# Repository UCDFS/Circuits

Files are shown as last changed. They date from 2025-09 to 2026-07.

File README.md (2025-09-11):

# UCDFS Circuits Repository

Welcome to the University College Dublin Formula Student (UCDFS) KiCad circuits repository! This is the central location for all our electronic circuit designs, schematics, and PCB layouts.

## About

This repository contains KiCad project files for various electronic circuits used in our Formula Student vehicle and projects. All designs are created using KiCad, an open-source electronic design automation (EDA) suite.

## Getting Started

1. **Clone this repository:**
   ```bash
   git clone https://github.com/UCDFS/Circuits.git
   cd Circuits
   ```

2. **Open a project in KiCad:**
   - Launch KiCad
   - Open the `.kicad_pro` file for the project you want to work on
   - The schematic (`.kicad_sch`) and PCB layout (`.kicad_pcb`) will be accessible from the project manager

3. **View/Edit Schematics:**
   - Click "Schematic Editor" in KiCad's main window
   - Or directly open the `.kicad_sch` file

4. **View/Edit PCB Layout:**
   - Click "PCB Editor" in KiCad's main window
   - Or directly open the `.kicad_pcb` file

## Repository Structure

```
├── README.md                     # This file
├── .gitignore                    # Git ignore rules for KiCad projects
└── [Project Name]/               # Individual circuit projects
    ├── [Project].kicad_pro       # KiCad project file
    ├── [Project].kicad_sch       # Schematic file
    └── [Project].kicad_pcb       # PCB layout file
```

## Contributing

When contributing new circuits or modifications:

1. **Create a new branch** for your work
2. **Organize projects** in clearly named directories
3. **Follow naming conventions:** Use descriptive names for projects and files
4. **Include all necessary files:** Ensure `.kicad_pro`, `.kicad_sch`, and `.kicad_pcb` files are included
5. **Document your work:** Add project details to a README in each circuit subfolder

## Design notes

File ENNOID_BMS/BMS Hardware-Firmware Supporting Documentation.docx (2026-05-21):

Main Master Slave IsoSPI configuration with detailed analysis on pin setup

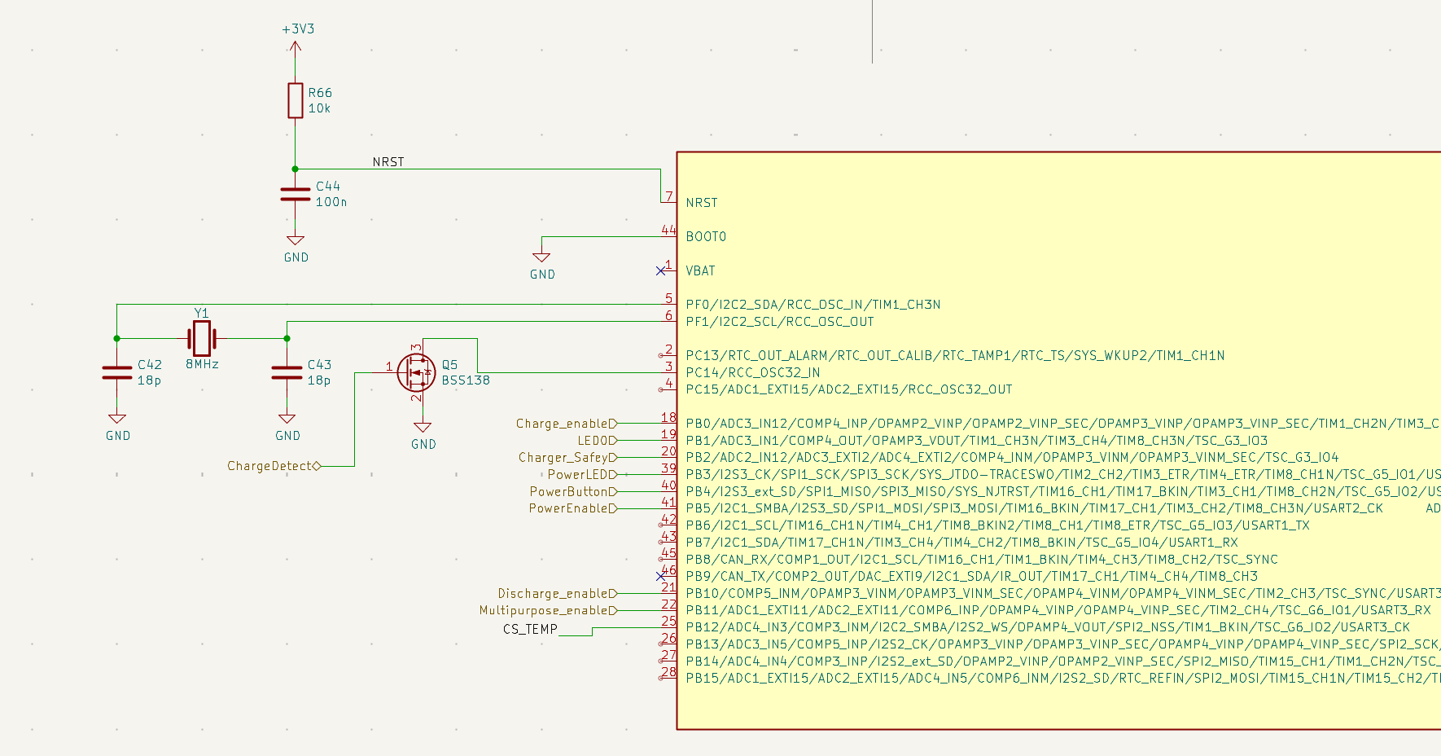
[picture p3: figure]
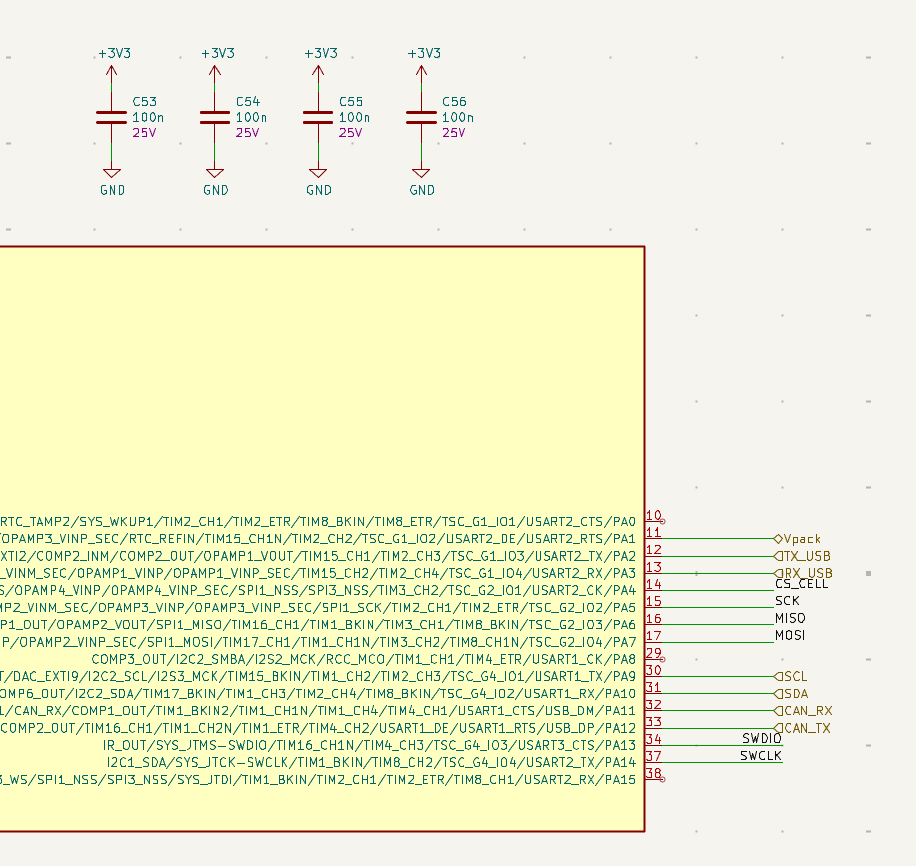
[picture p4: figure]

Fig 1 & 2. Master board STM32 pin configuration

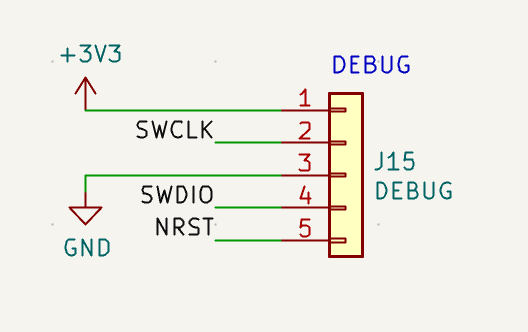
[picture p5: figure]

Fig 3. Flashing/Debug input connector

The STM32F303 is the master-board controller. It runs the BMS state machine, communicates with both isoSPI chains, reads local analogue/digital status signals, controls enable/safety outputs, and provides CAN/USB/debug interfaces. It is powered from +3V3, uses an 8 MHz HSE crystal, boots from user Flash with BOOT0 tied low, and is programmed/debugged through SWDIO/SWCLK.

Signal | STM32 pin | Type | Firmware role
CS_CELL | PA4 | SPI CS output / GPIO output | Selects the cell-chain LTC6820. Active-low chip select.
CS_TEMP | PB12 | SPI CS output / GPIO output | Selects the temperature-chain LTC6820. Active-low chip select.
SCK | PA5 | SPI bus | Shared SPI clock to both LTC6820 bridges.
MISO | PA6 | SPI bus | Shared SPI data from selected LTC6820 back to STM32.
MOSI | PA7 | SPI bus | Shared SPI data from STM32 to selected LTC6820.
Vpack | PA1 | ADC input | Load-side HV bus measurement after contactors/precharge.
ChargeDetect | PC14 | GPIO input | Charger present / charger wake reason.
Charge_enabled | PB0 | GPIO output | Charge permission/control output.
LED0 | PB1 | GPIO output | Status LED / indicator output.
Charger_Safety | PB2 | GPIO output | Charger safety/permission output.
PowerLED | PB3 | GPIO output | Power/status LED output.
PowerButton | PB4 | GPIO input | User power-button monitor input.
PowerEnable | PB5 | GPIO output | Firmware power latch / keep-alive output.
Discharge_enable | PB10 | GPIO output | Firmware discharge permission into the shutdown circuit. Downstream signal is active-low through the MOSFET stage. This is not a direct discharge relay driver.
Multipurpose_enable | PB11 | GPIO output | Firmware permission output into shutdown circuit. Downstream signal is active-low through the MOSFET stage. This replaces the old ENNOID precharge meaning and must not be used as a precharge relay output.
TX_USB | PA2 | UART TX | USB debug/config UART transmit to CP2104.
RX_USB | PA3 | UART RX | USB debug/config UART receive from CP2104.
SCL | PA9 | I²C SCL | I²C clock for ISL28022 / local I²C devices.
SDA | PA10 | I²C SDA | I²C data for ISL28022 / local I²C devices.
CAN_RX | PA11 | CAN RX | Vehicle CAN receive.
CAN_TX | PA12 | CAN TX | Vehicle CAN transmit.
SWDIO | PA13 | Debug | Serial Wire Debug data/programming.
SWCLK | PA14 | Debug | Serial Wire Debug clock/programming.
NRST | NRST pin | Reset | Active-low MCU reset; pulled up by 10 kΩ and filtered by 100 nF.
BOOT0 | BOOT0 pin | Boot config | Tied low, so MCU boots from user Flash.
HSE crystal | PF0/PF1 | Clock | 8 MHz external crystal input/output.

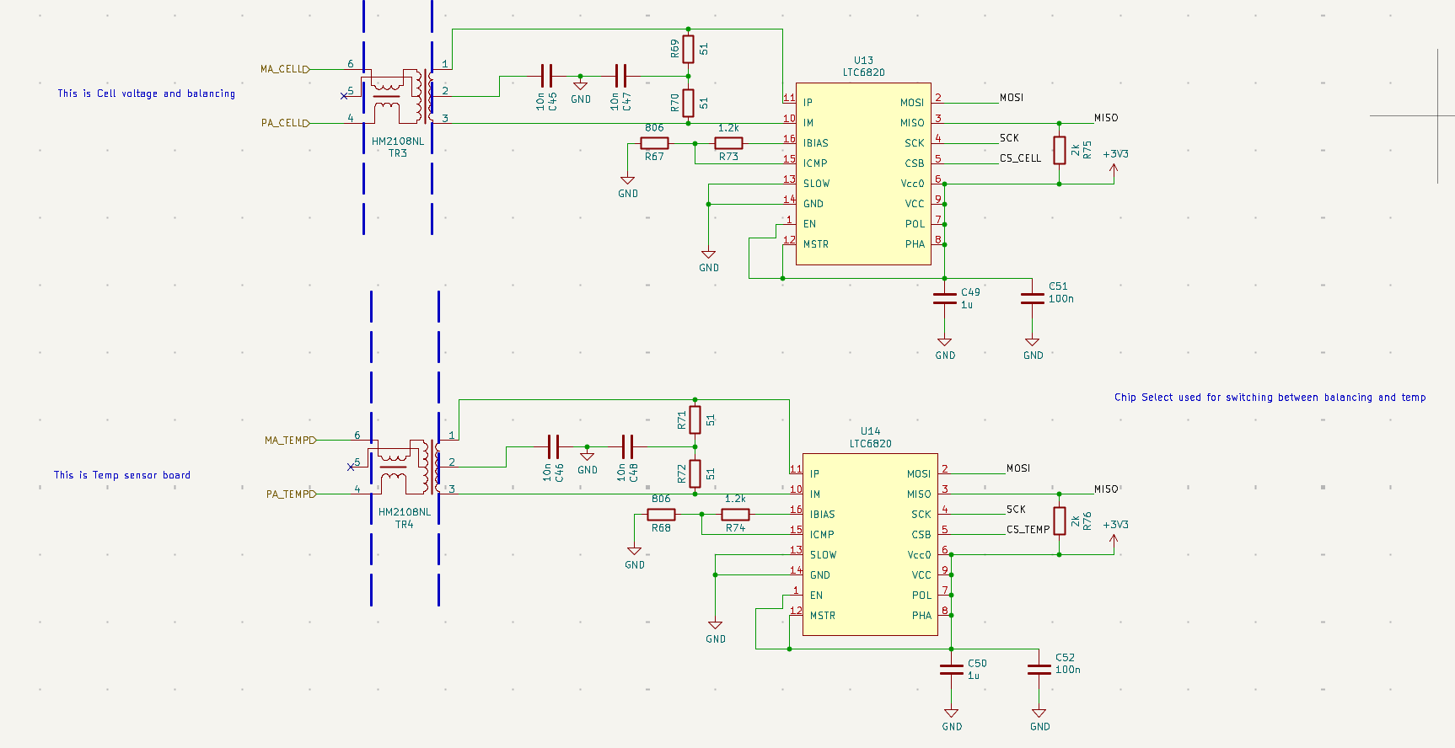
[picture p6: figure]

Fig 4. Master LTC6820 Cell and Temp Configuration

Each LTC6820 converts the STM32’s 3.3 V SPI bus into transformer-coupled isoSPI. The cell and temperature chains use separate LTC6820 bridges with shared SPI lines and independent chip selects, `CS_CELL` and `CS_TEMP`. Firmware must assert only one chip select at a time. Both bridges are configured as master-side isoSPI devices, with `MSTR` tied high, `VDD/VDDS` tied to +3V3, `PHA/POL` tied high for SPI mode 3, `SLOW` tied low, and `EN` tied low to allow automatic idle/wake behaviour.

The isoSPI bias network uses 1.2 kΩ from IBIAS to ICMP and 806 Ω from ICMP to GND. Since IBIAS regulates to approximately 2 V, total RBIAS is 2.006 kΩ and the bias current is approximately 1 mA. The IP/IM drive current is therefore approximately 20 mA. ICMP is approximately 0.8 V, giving a receiver threshold of approximately ±0.4 V. The transformer-side 51 Ω + 51 Ω network provides roughly 102 Ω differential termination.

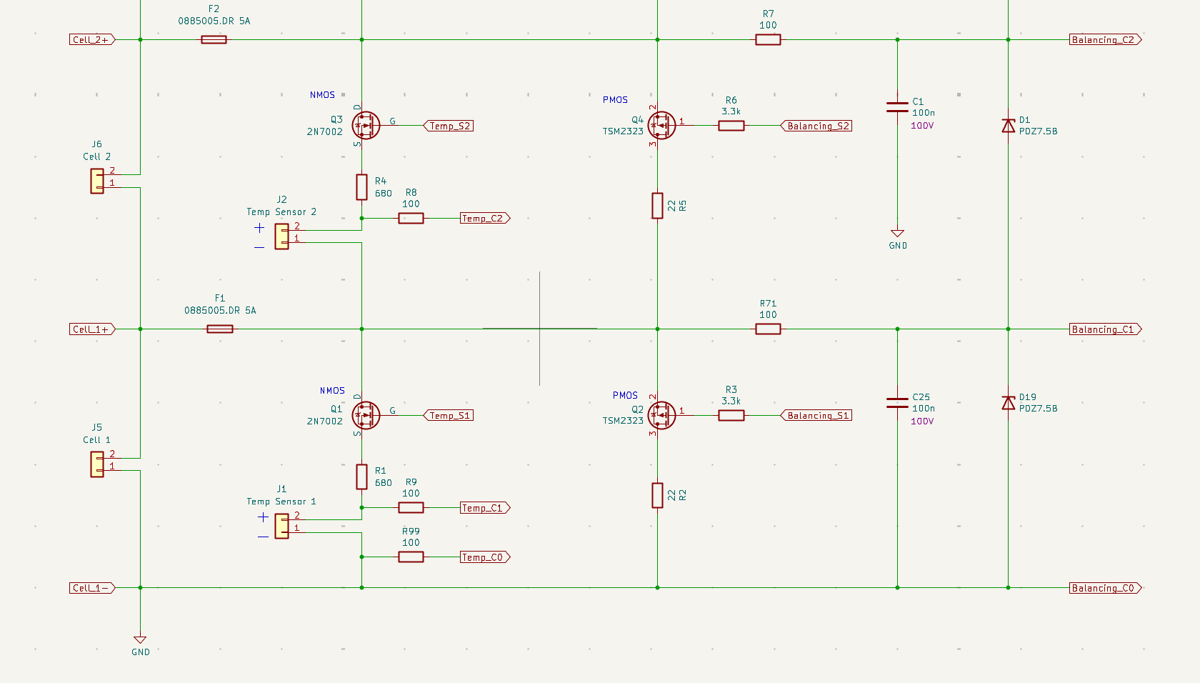
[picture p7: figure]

Fig 5. Slave Board full electrical connection schematic

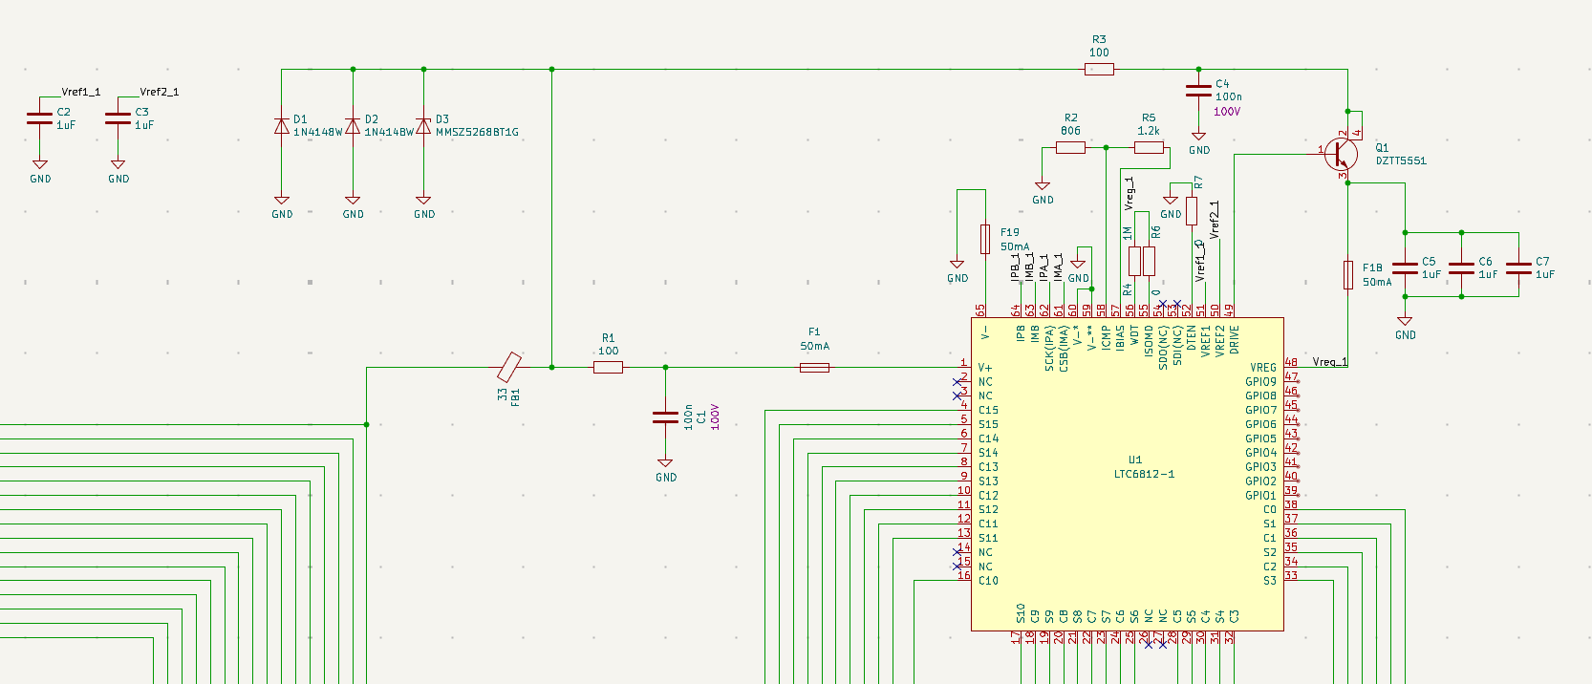
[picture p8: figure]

Fig 6. Slave LTC6812 configuration

Each slave LTC6812 floats with its local cell segment. `V+` and `V−` define the local stack supply domain and are not referenced to MCU ground. `C0–C15` measure differential cell/sensor voltages. On the cell-voltage chain, these are real cell voltages and `S1–S15` provide passive balancing control. On the temperature chain, the same measurement inputs are treated as analogue temperature-sensor voltages and S pins are used as an enable/disable switch

Temperature Measurement Slave Chain

The temperature chain uses a separate LTC6812 daisy chain from the cell-voltage chain. It is not used for balancing.

Each Enepaq temperature sensor behaves as a temperature-variable shunt reference. The sensor is current-limited through a 680 Ω path and its voltage is read by the LTC6812 C-input pair. The corresponding LTC6812 S output controls a MOSFET that enables the sensor-bias current only during measurement. After measurement, the S outputs are disabled to minimise parasitic discharge.

Firmware sequence:

1. select CS_TEMP

2. enable the required TEMP-chain S outputs as sensor-bias enables

3. allow settling based on RC time constant

4. start LTC6812 conversion

5. read C-input voltages

6. disable TEMP-chain S outputs

7. convert sensor voltage to temperature using the Enepaq datasheet table

The TEMP-chain S outputs are not balancing outputs. Cell balancing commands must never target the TEMP chain.

The LTC6812 is configured for isoSPI mode by tying `ISOMD` to `VREG_1` through a 0 Ω link. `IPA/IMA` and `IPB/IMB` form the two daisy-chain isoSPI ports. The bias network again uses 1.2 kΩ + 806 Ω, giving approximately 1 mA IBIAS, 20 mA isoSPI drive current, 0.8 V ICMP, and ±0.4 V receiver threshold. `WDT` is weakly pulled to `VREG_1` through 1 MΩ. `DTEN` is tied to `V−`, disabling the autonomous discharge timer, so balancing timing must be handled by firmware.

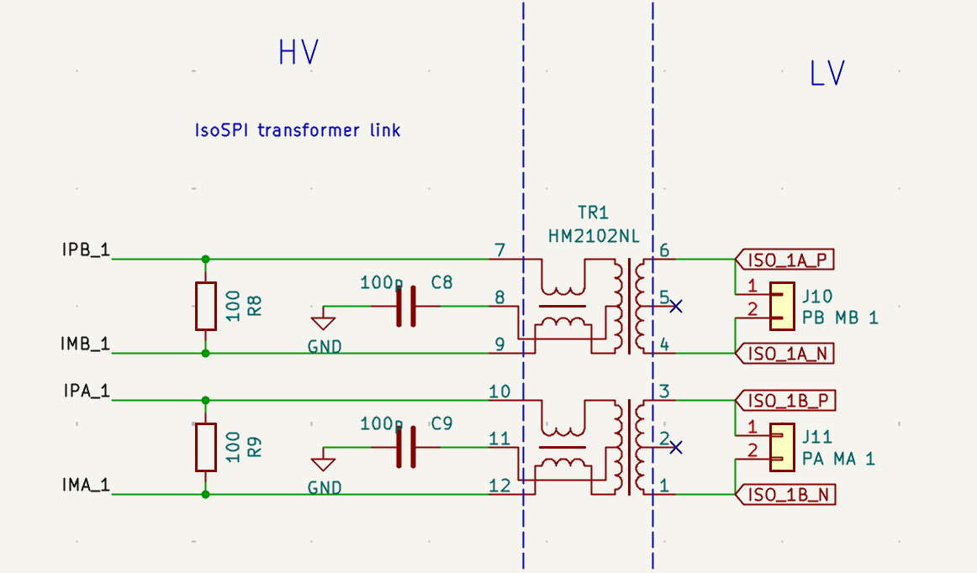
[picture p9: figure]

Fig 7. IsoSPI transformer link

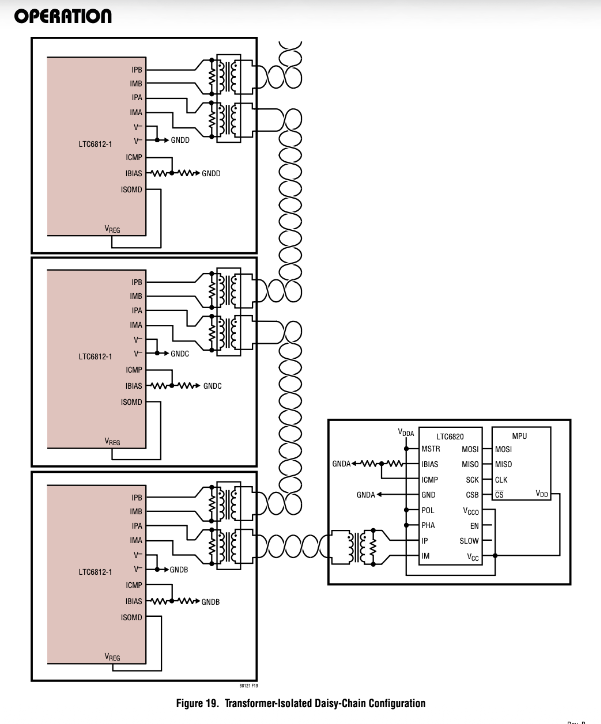
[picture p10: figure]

Fig 8. High level topology for daisy chain configuration for master and slave

Master board topology

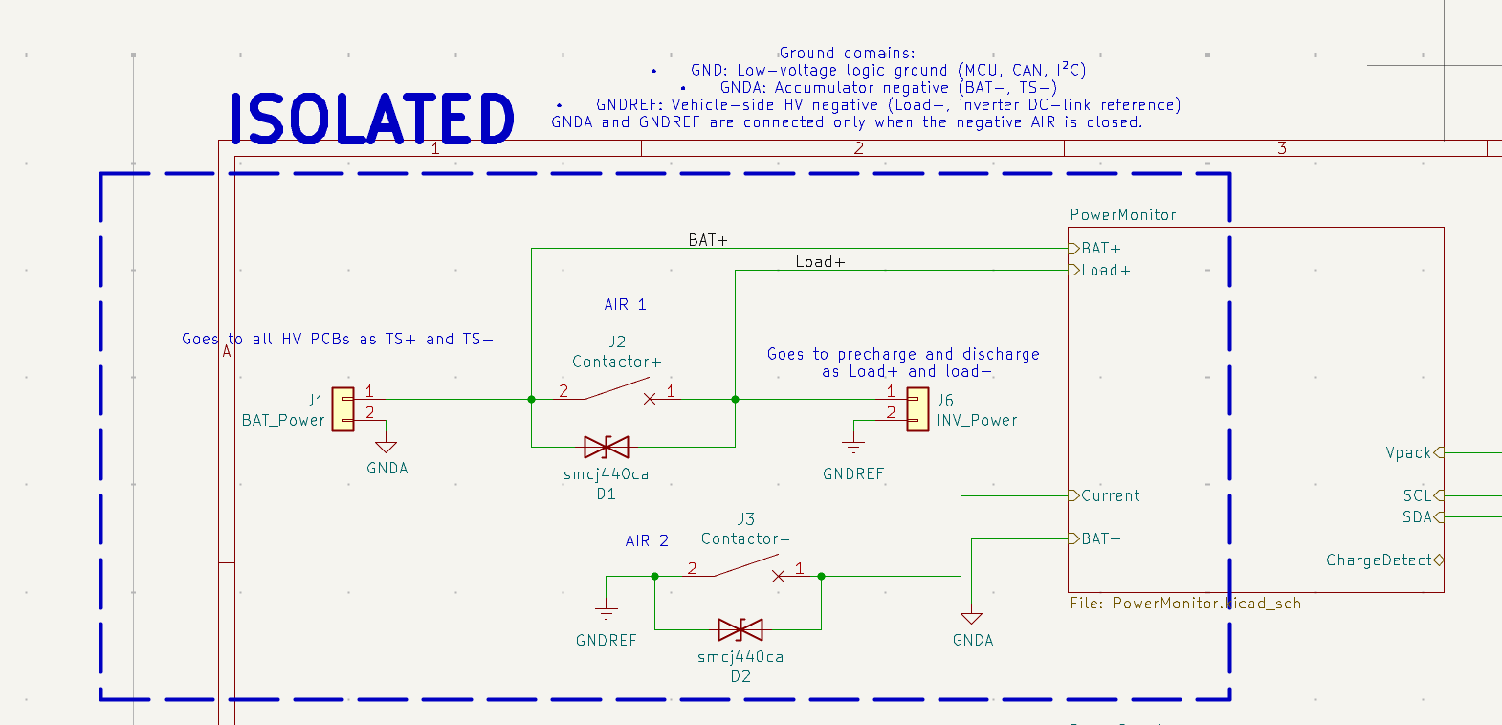
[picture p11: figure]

Fig 9. AIR Contact to PowerMonitor subsystem

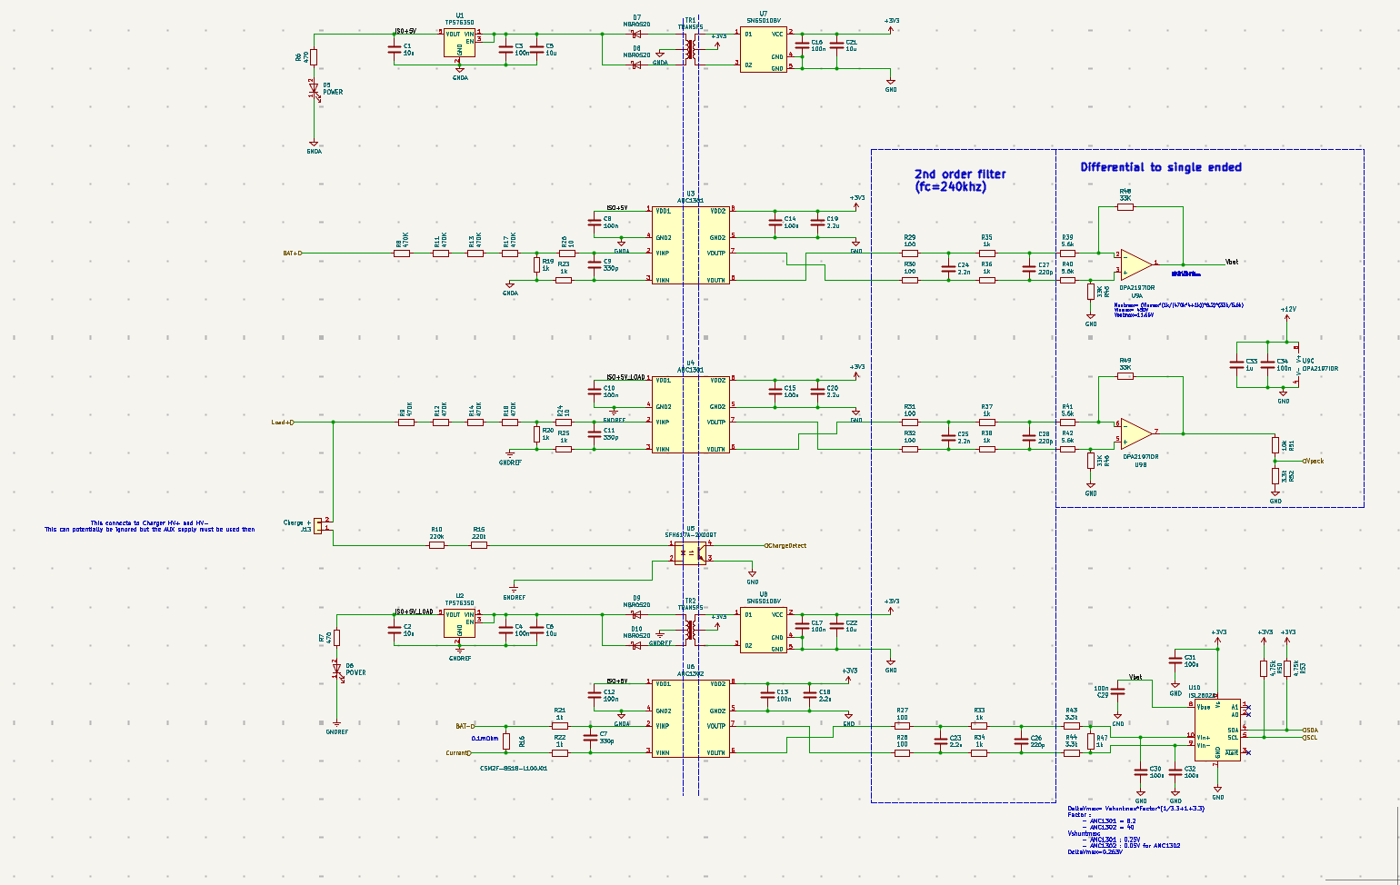
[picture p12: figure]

Fig 10. PowerMonitor configuration

The Power Monitor subsystem measures battery-side voltage, load-side voltage, shunt current, and charger presence while maintaining galvanic isolation between HV domains and MCU ground. The relevant domains are `GNDA` for the accumulator side, `GNDREF` for the load/inverter side, and `GND` for MCU logic. `GNDA` and `GNDREF` are only connected when the negative AIR is closed, so `BAT+` and `Load+` must be measured as separate physical nodes.

Measurement | Signal to firmware | Hardware path | Firmware use
Battery-side HV | ISL28022 over I²C | BAT+ divider → AMC1301 → filter → OPA2197 → Vbat → ISL28022 Vbus | Battery-side pack voltage before contactors
Load-side HV | STM32 ADC input Vpack | Load+ divider → AMC1301 → filter → OPA2197 → divider → Vpack | Load-side/precharge bus voltage
Current | ISL28022 over I²C | 0.1 mΩ shunt → AMC1302 → filter/scaling → ISL28022 Vin+ / Vin− | Charge/discharge current
Charger present | STM32 GPIO ChargeDetect | HV charger input → high-value resistors → optocoupler | Charger wake/state input

Both HV voltage dividers use four 470 kΩ resistors over 1 kΩ, giving approximately 1.88 MΩ / 1 kΩ and a divider ratio of about 1/1881. At 500 V this produces approximately 266 mV at the isolation amplifier input. Firmware must convert ADC readings using the complete analogue chain, not just the divider ratio.

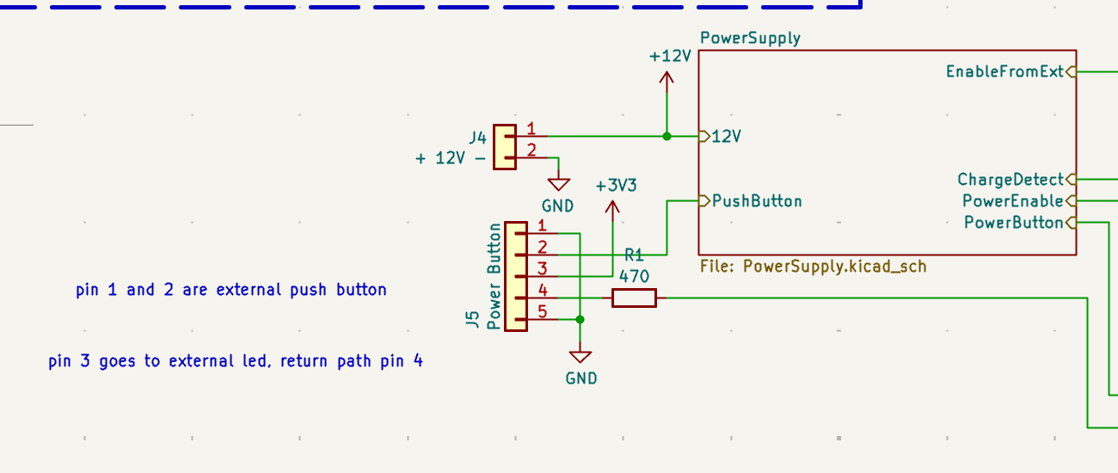
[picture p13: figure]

Fig 11. Power supply subsystem

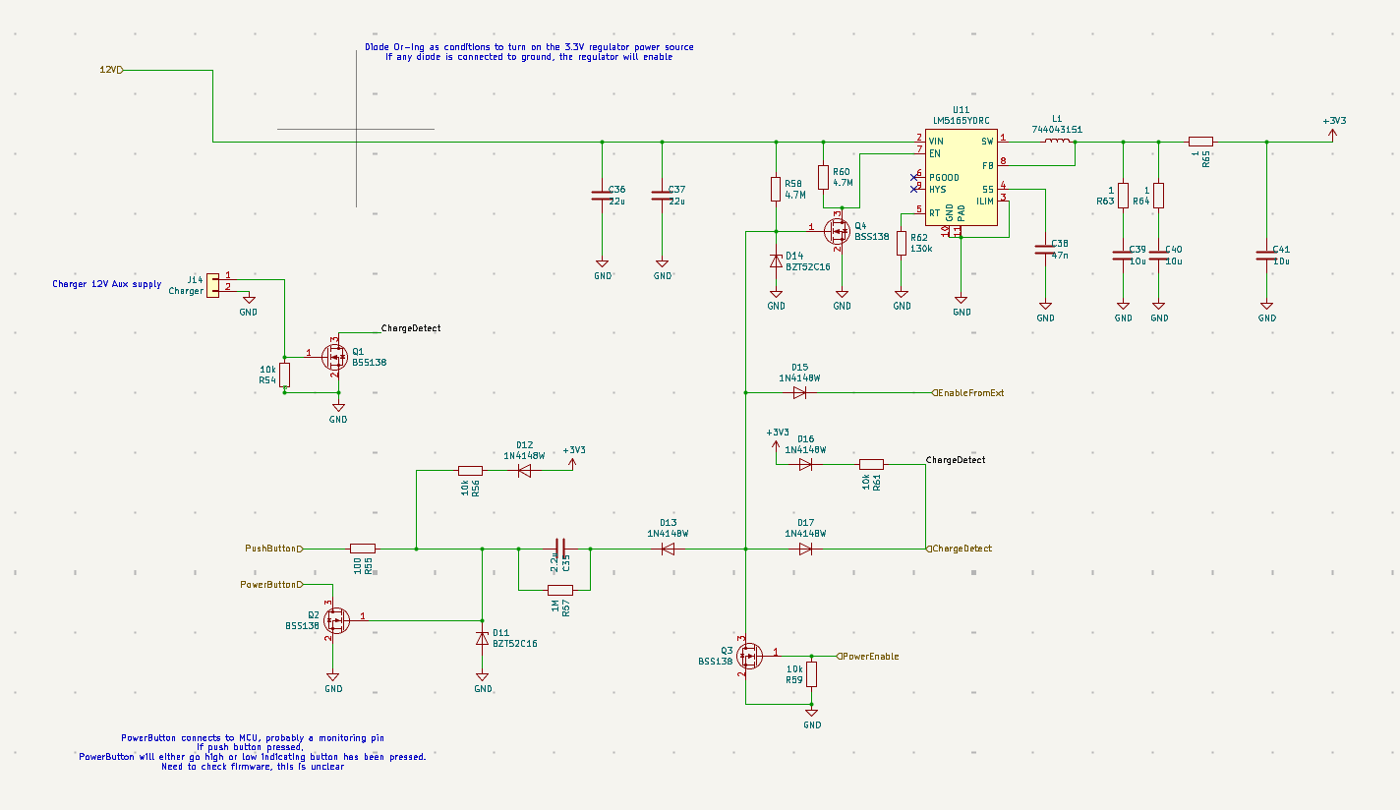
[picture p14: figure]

Fig 12. Power Supply Diode-oring network

The Power Supply subsystem generates +3V3 from external +12V using U11, an LM5165 buck regulator. The regulator is not always-on; its enable path is controlled by a diode-OR power-latch network. Valid wake/hold sources include external enable, the power button, charger detection, USB/CAN-related enable request, and firmware-held `PowerEnable`.

The intended sequence is: a hardware wake source enables the regulator, +3V3 rises, the STM32 boots, firmware validates the wake reason and basic system state, then asserts `PowerEnable` to keep the board alive. During shutdown, firmware disables safety/actuator outputs, stores required state, and releases `PowerEnable`.

Signal | Role
PowerButton | user input / wake source
PowerEnable | firmware power latch
ChargeDetect | charger wake source
EnableFromExt | external hardware wake source
EnableRequest | USB/CAN-side wake/request path

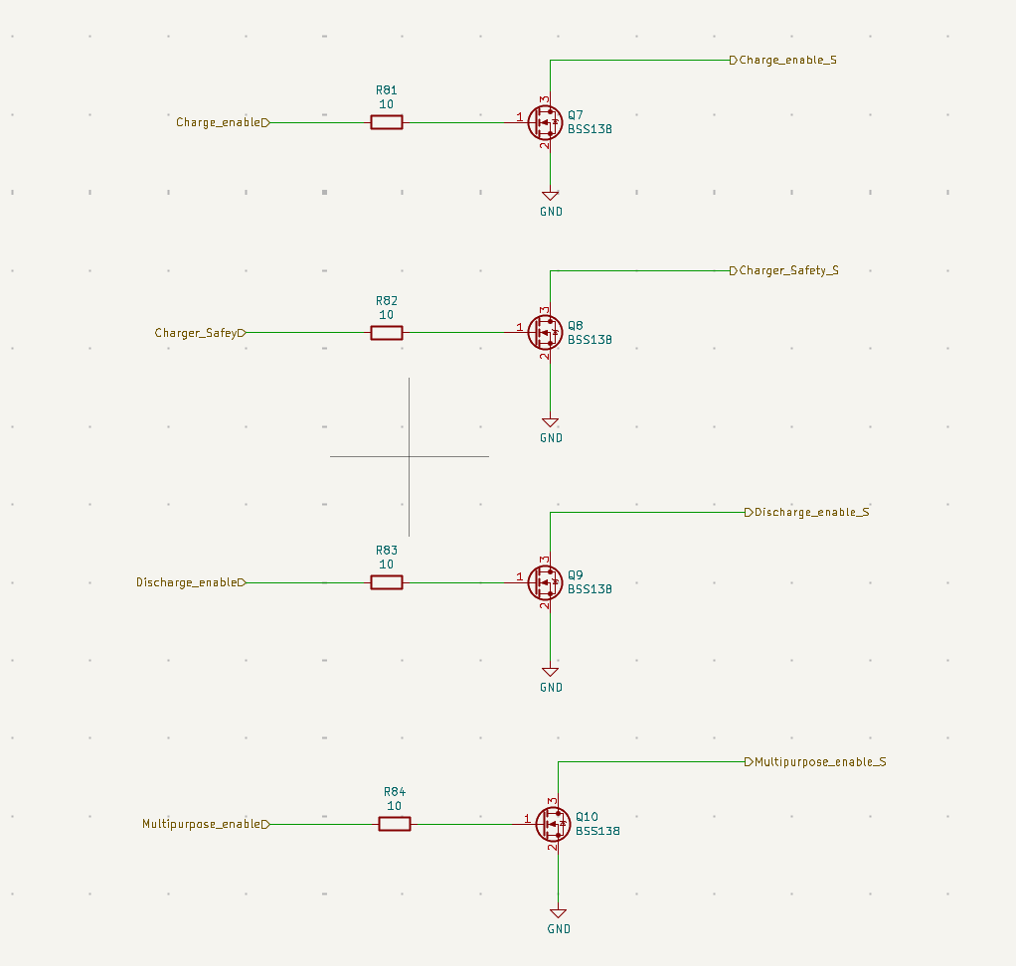
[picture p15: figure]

Fig 13. Shutdown conditions

The shutdown circuit combines `Multi_purpose_enable` and `Discharge_enable` using U2, a SN74AHC1G02 two-input NOR gate. Both inputs are pulled up to +5 V through 10 kΩ resistors, so the default state is inactive unless the BMS actively pulls the signals low. The NOR output is `AMS_OK`, so `AMS_OK` is high only when both inputs are low. These signals must therefore be treated in firmware as active-low permissions: `Multi_purpose_enable` means the master/BMS is alive and healthy, while `Discharge_enable` means the pack is safe to discharge.

AMS_OK = !Multi_purpose_enable && !Discharge_enable on the shutdown circuit

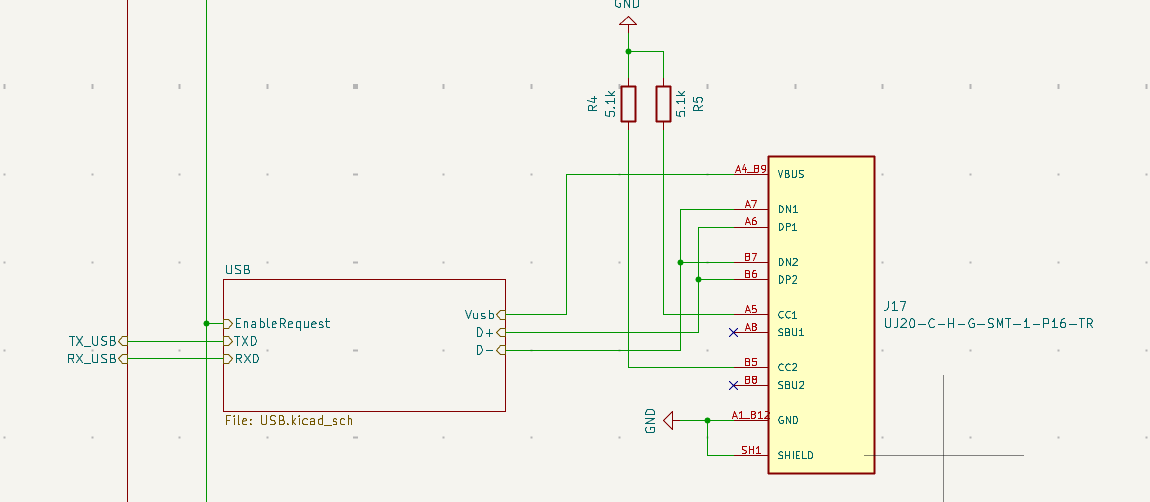
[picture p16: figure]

Fig 14. USB port

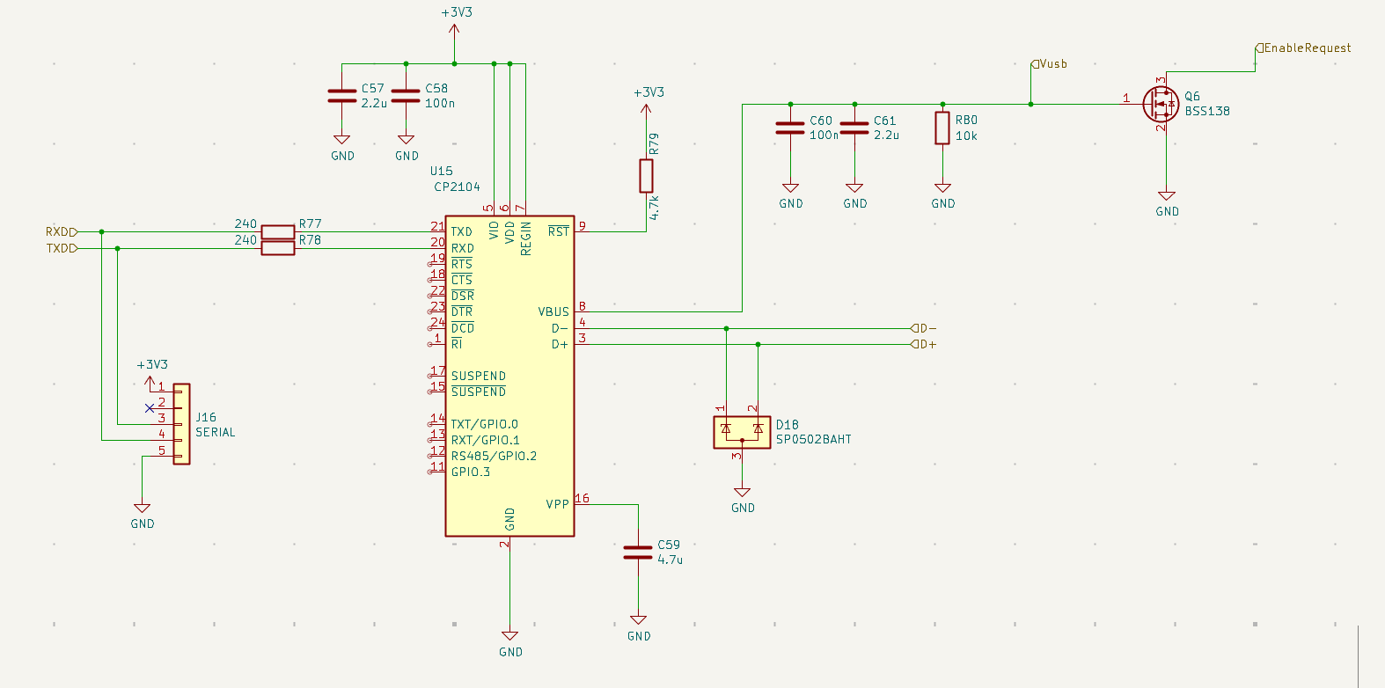
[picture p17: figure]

Fig 15 USB to UART bridge

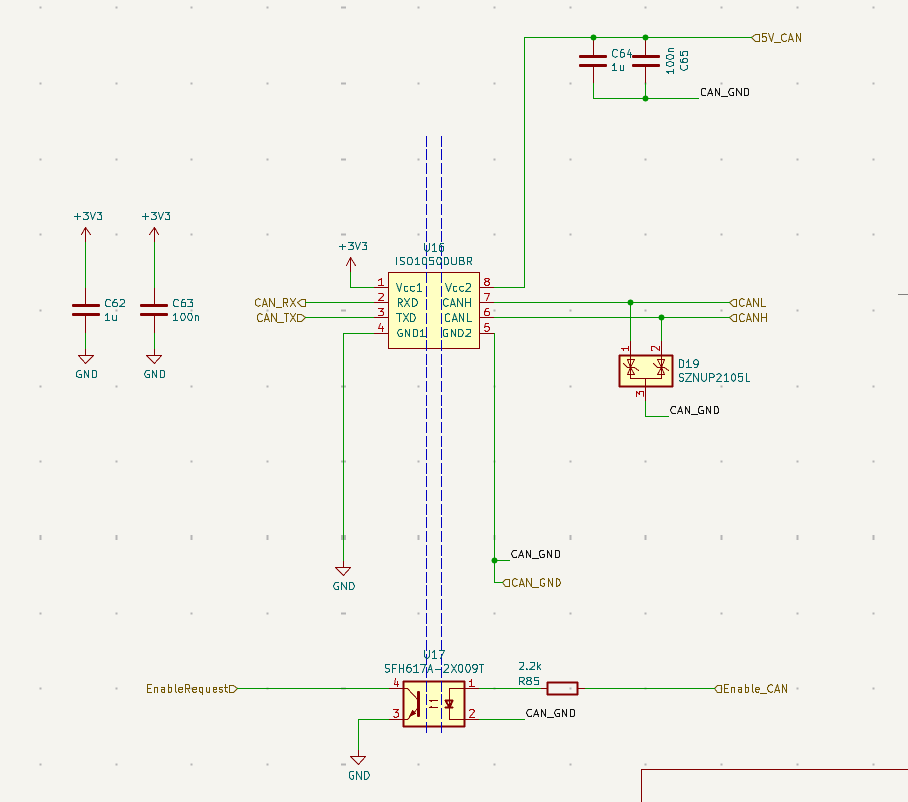
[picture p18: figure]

Fig 16. CAN transceiver

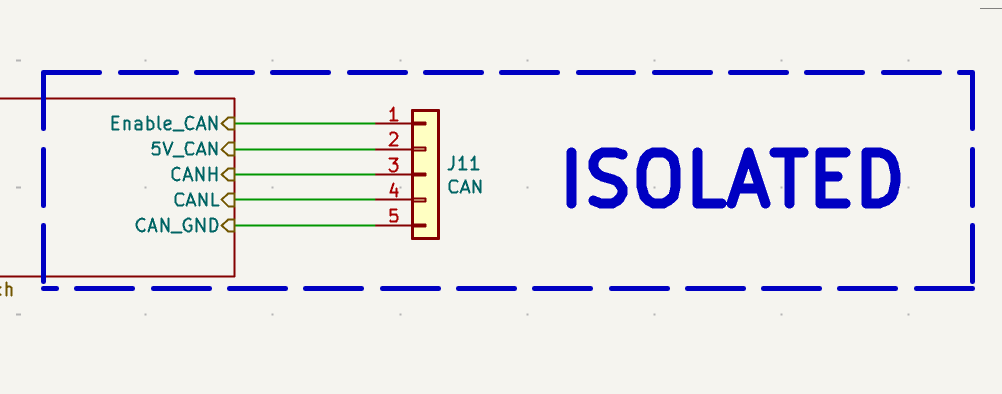
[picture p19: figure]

Fig 17. CAN ports

USB is provided through a CP2104 USB-to-UART bridge and should be treated as a debug/configuration/logging interface. USB VBUS can also generate an enable request, so plugging in USB may wake the BMS. This path is not safety-critical and must not be used as sole authority for charge/discharge decisions.

CAN is provided through an isolated ISO1050 transceiver. The STM32 side uses `CAN_RX`/`CAN_TX` referenced to MCU ground, while the bus side uses isolated `5V_CAN`, `CAN_GND`, `CANH`, and `CANL`. `Enable_CAN` is driven across an optocoupler from `EnableRequest`, allowing the MCU to request or indicate CAN-side enable state without tying MCU ground to CAN ground.

## Hardware Changes from ENNOID Design

Additional ISOSPI chain for temp sensing according to enepaq cells added. Cooling, precharge relay, and direct discharge relay control removed. Switched to generic mosfet control signals to the shutdown circuit. USB type A changed to USB type C. buzzer removed. OLED removed. Thermistor GPIO readings removed from slave boards.

## minimum firmware fault table

The current migrated firmware implements a centralized conservative fault model. The table below describes the intended detection source and permission effect; thresholds and final vehicle policy still require hardware validation and safety review.

Fault condition | Detection source | Firmware response / permission effect

Cell OV soft | CELL LTC6812 voltage stats/config threshold | blocks charge

Cell OV hard | CELL LTC6812 voltage stats/config threshold | critical fault, blocks MasterOk/charge/discharge as configured

Cell UV soft | CELL LTC6812 voltage stats/config threshold | blocks discharge

Cell UV hard | CELL LTC6812 voltage stats/config threshold | critical fault

Cell read invalid | LTC6812 PEC/missing response | blocks permissions conservatively

Cell open-wire | LTC6812 ADOW diagnostic | blocks balancing and relevant permissions

Temperature read invalid | TEMP LTC6812 read/conversion validity | blocks temp-dependent permissions

Temperature overlimit | Enepaq converted temp | blocks charge/discharge depending policy

ISL read invalid | ISL28022 I²C failure | blocks power-monitor-dependent decisions

Vpack read invalid | PA1 ADC failure/out of range | blocks precharge/discharge validation

Precharge timeout | Vbat/Vpack relationship over time | fault, do not proceed to load enabled

Welded contactor suspicion | Vpack high when expected discharged | fault

Internal fatal | firmware/state-machine fatal path | deassert permissions

Truth Table

Condition | MasterOk | DischargePermission | ChargePermission | ChargerSafety

Boot/reset/default | off | off | off | off

Cell read invalid | off | off | off | off

Open-wire fault | off/block | off/block | off/block | off/block

Temp invalid | depends on masks, conservative block | block if required | block if required | block if charge blocked

Soft UV | maybe MasterOk allowed | off | allowed if otherwise safe | allowed if charging safe

Soft OV | maybe MasterOk allowed | allowed if otherwise safe | off | off

Hard OV/UV | off | off | off | off

Precharge incomplete | conditional | off | off | off

Load enabled and healthy | on | on | optional | optional

Charging healthy | maybe off/on depending shutdown role | off | on | on

Error/power-down | off | off | off | off

Appendix: Original ENNOID Firmware Gap Analysis

This appendix documents the original gap analysis before the migration. It is retained for traceability only. It no longer describes the current firmware state.

Existing Firmware State

A. Architecture
Key refs: Main/main.c (line 30), modOperationalState.c (line 39), modPowerElectronics.c (line 22), mainDataTypes.h (line 479)

main() does HAL_Init(), SystemClock_Config(), power-latch on via modPowerStateInit(P_STAT_SET), starts IWDG, loads config/SoC from EEPROM, then inits commands/UART/CAN/effects/power-electronics/operational-state/HiAmp in that order. The superloop is modEffectTask(), modPowerStateTask(), modOperationalStateTask(), modUARTTask(), modCANTask(), modHiAmpTask(), watchdog refresh, and modPowerElectronicsTask(); on each successful measurement pass it runs modStateOfChargeProcess().

State machine states are OP_STATE_INIT, CHARGING, PRE_CHARGE, LOAD_ENABLED, BATTERY_DEAD, POWER_DOWN, EXTERNAL, ERROR, ERROR_PRECHARGE, BALANCING, CHARGED, FORCEON. Existing protection is centered in modPowerElectronicsSubTaskVoltageWatch(): soft UV blocks discharge, soft OV blocks charge, hard UV/OV eventually sets PACK_STATE_ERROR_HARD_CELLVOLTAGE, which modOperationalStateTask() escalates to OP_STATE_ERROR. Precharge timeout is handled in OP_STATE_PRE_CHARGE. Temperature protection is not active: modPowerElectronicsTask() comments out modPowerElectronicsSubTaskTemperatureWatch() and only computes temp stats/throttles. Comms interfaces present are USART2 packet protocol, CAN, SPI1 for LTC6803, I2C1/I2C2, plus OLED/buzzer/HiAmp support.

B. Hardware Mapping
Primary pin refs: mxconstants.h (line 44), stm32f3xx_hal_msp.c (line 126), driverHWPowerState.c (line 3), driverHWSwitches.c (line 3)

New signal | Existing firmware ref | Current config | Match | Required change
CS_CELL | LTC_CS_Pin, driverSWLTC6803 | PA4, GPIO CS for SPI1 | Yes | Reuse as cell-chain CS.
CS_TEMP | SDC_CS_Pin only | PB12, currently SD-card/SPI2 CS in CubeMX, unused by BMS logic | No | Repurpose PB12 as second LTC6820 CS and remove SD-card meaning.
SCK/MISO/MOSI | LTC_SCK/MISO/MOSI, driverHWSPI1Init() | PA5/PA6/PA7, SPI1 | Yes | Reuse bus. Note ambiguity: runtime driver is mode 3, but CubeMX MX_SPI1_Init() is CPHA=1EDGE, not mode 3.
Vpack | VoutSense_Pin, driverHWADCGetLoadVoltage() | PA1 ADC1_IN2 | Yes | Reuse as load-side/precharge bus voltage; recalibrate for new analogue chain and rename semantics.
ChargeDetect | P_STAT_CHARGE_DETECT, ChargeDetect_Pin | PC14 input | Yes | Likely reusable as-is.
PowerButton | P_STAT_BUTTON_INPUT, PowerButton_Pin | PB4 input pull-up in HW driver | Yes | Reuse, verify active level against new board.
PowerEnable | P_STAT_POWER_ENABLE, PowerEnable_Pin | PB5 output | Yes | Reuse latch logic.
Charge_enabled | SWITCH_CHARGE, ChargeEnable_Pin | PB0 output | Pin matches | Rebind semantics to charge permission output; verify polarity.
Charger_Safety | SWITCH_DRIVER, SwitchEnable_Pin | PB2 output | Pin matches, role does not | Change from “FET driver enable” to charger safety/permission.
Discharge_enable | SWITCH_DISCHARGE, DischargeEnable_Pin | PB10 output | Pin matches, polarity/role do not | Must become active-low shutdown permission, not active-high discharge relay/FET control.
Multipurpose_enable | SWITCH_PRECHARGE, PreChargeEnable_Pin | PB11 output | Pin matches, role does not | Must replace precharge function with active-low master/AMS permission.
TX_USB/RX_USB | BOOTLOADER_TX/RX, driverHWUART2 | PA2/PA3, USART2 | Yes | Reuse UART, rename from bootloader/OEM meaning to USB debug UART.
SCL/SDA | ISL_SCL/SDA, driverHWI2C2 | PA9/PA10, I2C2 | Yes | Reuse physical pins; keep/rename I2C2 abstraction as needed.
CAN_RX/CAN_TX | HAL_CAN_MspInit, modCANInit | PA11/PA12, CAN AF9 | Yes | Reuse.
ISL28022 | driverSWISL28022, ISL28022_MASTER_BUS=2 | Reads on I2C2 | Partly | Reuse driver shell, but improve init, error returns, scaling, and explicit Vbat/current semantics.
LTC6812/LTC680x driver | driverSWLTC6803 only | Single-chain LTC6803, 12-cell API | No | Replace or heavily refactor for LTC6812 + 15 channels + 2 chains.
cell balancing | modPowerElectronicsSubTaskBalaning(), driverSWLTC6803EnableBalanceResistors() | Single mask on one chain | Partly | Reuse algorithm ideas only for cell chain; hard-block balancing on temp chain.
temperature measurement | driverSWLTC6803ReadTempVoltages() + NTC conversion | 2 external + 1 internal LTC6803 temps + local STM32 NTC | No | Replace with second LTC6812 analogue-voltage chain and new conversion model.

C. Driver Reuse Assessment
Driver refs: driverSWLTC6803.h (line 9), driverSWLTC6803.c (line 6), driverHWSPI1.c (line 5)

- It supports 12 cells per IC only: driverSWLTC6803ReadCellVoltages(...[12]), NoOfCellsPossibleOnChip 12, default config noOfCells = 12.
- It does not support 15 cells per IC.
- It does not support 5 ICs in practice. driverSWLTC6803Init(..., totalNumberOfLTCs) stores a count, but modPowerElectronics.h hardcodes TotalLTCICs 1, the pack state array holds only 12 cells, and several read paths use [1][...] buffers.
- It does not support two independent isoSPI chains or two CS lines; all SPI coupling is hardwired to LTC_CS_Pin.
- SPI mode 3 is supported by driverHWSPI1Init() (CPOL=HIGH, CPHA=2EDGE), which matches LTC6820 mode 3. CubeMX SPI1 config does not match, so there is a split-brain risk.
- PEC checking exists in the LTC6803 driver, but callers mostly ignore the boolean return values, so the system does not currently turn PEC faults into a safe-state action.
- Open-wire command enums exist in driverSWLTC6803.h, but there is no call path using them. So diagnostics are not implemented at system level.
- Balancing control exists and writes DisChargeEnableMask on the LTC chain.
- Existing temperature support is old-style LTC6803 aux/thermistor handling plus one local STM32 NTC; that should be replaced, not extended, for a second LTC6812 analogue temp chain.

D. Required Firmware Changes

1. Pin/peripheral config changes: add CS_TEMP on PB12; repurpose PB11 from precharge to Multipurpose_enable; repurpose PB2 to Charger_Safety; keep PA1, PA2/3, PA9/10, PA11/12, PC14, PB4, PB5, PB0, PB10; remove OLED/buzzer/SD-card pin assumptions.
2. isoSPI/LTC driver changes: replace driverSWLTC6803 with LTC6812-capable code; support 5 devices x 15 measurements; support separate cell/temp chain selectors; enforce “only one CS low at a time”; make comms faults actionable.
3. Temperature-chain implementation: add second chain read path, analogue-voltage-to-temperature conversion, indexing/storage for 75 temps, and a hard guard so no balancing/config writes intended for cells reach the temp chain.
4. Power monitor / ISL28022 changes: keep ISL over PA9/PA10, but formalize Vbat and current reads, propagate I2C errors, and validate scaling against the new AMC1301/AMC1302 path.
5. Shutdown/AMS_OK logic changes: replace legacy charge/precharge/discharge contactor model with active-low permissions on PB11/PB10;
6. Removed feature cleanup: delete/disable OLED (modDisplay, driverSWSSD1306, I2C1 use), buzzer (driverHWStatus), SD-card/SPI2, slave thermistor assumptions, and any HiAmp/cooling artifacts not used on the new board.
7. CAN/USB changes: CAN pins already match; USB UART already matches electrically but should be renamed away from BOOTLOADER_TX/RX.
8. Fault logic changes: add temp-chain comms policy, open-wire handling, precharge Vbat/Vpack mismatch fault, welded-contactor suspicion, ISL I2C fault, and watchdog/fatal behavior that deasserts Multipurpose_enable.

E. Main Risks

- Output polarity is the biggest safety risk: current SWITCH_* logic is active-high, but new Multipurpose_enable and Discharge_enable must be treated as active-low permissions.
- PB11 currently means precharge. Reusing old code unchanged could accidentally drive the shutdown path as if it were a precharge relay.
- PB12 exists only as old SDC_CS_Pin; without a chain abstraction both CS lines could be asserted or left ambiguous.
- The current balancing path is global. If copied naively to dual chains, the temp chain could receive balancing/config writes.
- LTC comms PEC exists but is not turned into a fault response; today a bad PEC can be silently ignored by higher-level logic.
- Open-wire is declared but unused.
- Error_Handler() just loops; there is no explicit deassert of a future Multipurpose_enable.
- SPI config is ambiguous: custom driver is mode 3, CubeMX SPI1 is not. A future refactor could silently break isoSPI comms.
- Current ISL validity logic compares bus voltage to noOfCells * cellVoltageAverage within 1 V; that heuristic may be too brittle for 75 cells and the new analogue chain.
- modPowerElectronicsCheckPackSOA() sets packInSOA = packOutsideLimits, which reads inverted; it is also never the primary shutdown path.

F. Recommended Implementation Order

1. Make builds reproducible from one path only. Today the repo is Keil/CubeMX-centric, with .uvprojx and .ioc files but no checked-in GCC/CMake build.
2. Update the pin map and rename GPIO abstractions to the new contract.
3. Introduce a two-chain isoSPI HAL: shared SPI bus, CS_CELL, CS_TEMP, mutual exclusion.
4. Get cell-chain LTC6812 readout working first, with PEC failure surfaced.
5. Get temp-chain LTC6812 readout working second, read-only by construction.
6. Bring up ISL28022 Vbat/current and verify PA1 Vpack.
7. Replace legacy precharge/discharge outputs with explicit shutdown/AMS permission logic and verified polarity.
8. Implement the fault table and safe-state actions.
9. Validate CAN and USB debug paths after the safety/output changes.
10. Run a hardware bring-up checklist: boot defaults, one-CS-at-a-time, cell read, temp read, ISL read, charger detect, power latch, watchdog reset, UV/OV/temp/comms/open-wire fault injection.

Open Questions

- The Enepaq voltage-to-temperature conversion is implemented from the repo-provided datasheet table using lookup/interpolation. The remaining open questions are physical channel mapping, required channel mask, and sensor-bias settling time.The required policy for temp-chain comms faults is still “likely disable charge/discharge or derate; policy TBD”.
- I did not find an existing build script/toolchain lockfile; choosing Keil-only vs generating a GCC/CMake path is an upfront decision.

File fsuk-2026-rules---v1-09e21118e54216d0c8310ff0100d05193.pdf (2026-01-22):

© 2026 IMechE | 1 | Formula Student 2026 Rules

## FORMULA STUDENT 2026 RULES

© 2026 IMechE | 2 | Formula Student
CV4 | SHUTDOWN SYSTEM | 103
CV5 | LV HYBRID SYSTEM | 104
SECTION EV – ELECTRIC VEHICLES | 106
EV1 | DEFINITIONS | 106
EV2 | ELECTRIC POWERTRAIN | 107
EV3 | GENERAL REQUIREMENTS | 108
EV4 | TRACTIVE SYSTEM | 109
EV5 | TRACTIVE SYSTEM ENERGY STORAGE | 117
EV6 | EV SHUTDOWN CIRCUIT AND SYSTEMS | 124
EV7 | CHARGERS | 127
EV8 | TRACTIVE SYSTEM ACCUMULATOR CONTAINER HAND CART | 128
EV9 | ELECTRICAL SYSTEM FORM | 129
SECTION AFV – ALTERNATIVE FUEL VEHICLES | 130
AFV1 ALTERNATIVE FUEL VEHICLES | 130
SECTION IN – TECHNICAL INSPECTIONS | 132
IN1 | GENERAL | 132
IN2 | MOTORSPORT UK SAFETY INSPECTION | 135
IN3 | [EV ONLY] ACCUMULATOR INSPECTION | 136
IN4 | [EV ONLY] ELECTRICAL INSPECTION | 137
IN5 | MECHANICAL INSPECTION | 138
IN6 | [DV ONLY] AUTONOMOUS SYSTEM INSPECTION | 139
IN7 | TILT TEST | 140
IN8 | VEHICLE WEIGHING | 141
IN9 | [EV ONLY] RAIN TEST | 142
IN10 NOISE TEST | 143
IN11 BRAKE TEST | 144
IN12 POST EVENT INSPECTION | 145
IN13 DRIVER EGRESS TEST | 146
SECTION S – STATIC EVENTS | 147
S1 | STATIC EVENT NO-SHOW PENALTY | 147
S2 | BUSINESS PLAN PRESENTATION (BPP) – FS CLASS AND CONCEPT CLASS | 148
S3 | COST AND MANUFACTURING EVENT – FORMULA STUDENT CLASS | 151
S4 | COST AND MANUFACTURING EVENT – CONCEPT CLASS | 157

© 2026 IMechE | 3 | Formula Student
S5 | ENGINEERING DESIGN EVENT – FORMULA STUDENT CLASS | 159
S6 | ENGINEERING DESIGN EVENT – CONCEPT CLASS | 161
S7 | LAP TIME SIMULATION (LTS) | 162
SECTION D – DYNAMIC EVENTS | 167
D1 | DYNAMIC EVENTS GENERAL | 167
D2 | DRIVING RULES | 168
D3 | WEATHER CONDITIONS | 171
D4 | SKIDPAD EVENT | 172
D5 | ACCELERATION EVENT | 175
D6 | AUTOCROSS EVENT | 178
D7 | ENDURANCE AND EFFICIENCY EVENT | 180
D8 | [DV ONLY] TRACKDRIVE EVENT | 186
D9 | DYNAMIC EVENTS PENALTIES | 188
SECTION FC – FUTURE CHANGES | 190

© 2026 IMechE | 4 | Formula Student

### INTRODUCTION

Formula Student UK (FS) is an educational challenge organised by the Institution of Mechanical Engineers (IMechE) for the purpose of educating and preparing students of engineering and other disciplines for their future careers.

The competition is governed and executed in line with four key values:

1. Safety – to maintain the highest standards of safety throughout the event.
2. Education – to focus on providing the best educational experience for all those involved, including competitors, volunteers and visitors.
3. Openness – to be open to collaboration with other competitions and parties, to embrace new ideas and to allow different vehicle concepts to compete together within a common rule set.
4. Inclusive – to deliver an event that allows all teams to be at their best: new or established, elite or amateur, domestic or international.

The IMechE is supported by volunteers from Industry and Academia that together form the Formula Student Organising Committee (the Committee). The Committee includes the IMechE Formula Student Project Manager and Project Executive and volunteers: Chairmen, Chief Judge, Clerk of the Course, Head Judges, Chief Scrutineers, Dynamic Events Captains and other volunteers representing key functional areas. The Committee is supported by sub-committees for Scrutineering, Dynamic Events, Electric Vehicles and FS-AI. The rule set for the competition is continuously reviewed by the Committee and updated at least once a year with the aim of providing the best educational experience for students and volunteers whilst maintaining the highest standards for safety.

FS operates under a permit from the national motorsport governing body, Motorsport UK. The dynamic events are overseen by a licensed Clerk of the Course, supported by nationally registered marshals and officials as well as volunteers with industrial and/or Formula Student experience.

The static events are judged by a mix of experienced engineering industry professionals (from backgrounds including motorsport, automotive, aerospace and supply chain partners) as well as recent graduates and learned academic authorities.

The Competition is composed of three classes:

- Formula Student (FS Class),
- FS-AI (Formula Student Artificial Intelligence),
- Concept Class.

The Formula Student Rules consist of two documents:

- Formula Student 2026 Rules (this document),
- Formula Student AI 2026 Rules (driverless vehicle regulations).

The scope of Formula Student 2026 Rules covers FS Class, Concept Class and any FS-AI Class regulations that are common and integrated with FS Class (i.e., a single rule within a rules section,

© 2026 IMechE | 5 | Formula Student

denoted by [DV Only]). All FS-AI specific rules sections are defined in the Formula Student AI 2026 Rules. Therefore, when understanding the regulations for FS-AI class, both rule sets must be considered.

These Formula Student UK 2026 Rules are written to be as closely aligned as is practicable with the ‘Formula Student Rules 2026/FSG Rules’, with specific targeted changes for the following reasons:

- Mitigation of safety risks based on experience from the UK events, partner events and Motorsport UK regulator,
- Relaxation of rules, in some but not all cases, which create a barrier to entry for FSAE based vehicles,
- UK specific administrative items required to meet the educational goals of the competition as defined by the IMechE and the Committee.

FS Class permits vehicles designed to Formula Student Rules 2026/FSG Rules and Formula SAE Rules (FSAE), but must conform to all relevant Formula Student Rules as defined above.

FS-AI rules (Driverless Vehicles) define the regulations for the two driverless classes, where teams use their own vehicle (Autonomous Driving System Class - ADS) or the IMechE ADS-DV (Autonomous Driving System – Dedicated Vehicle) is used (Dynamic Driving Task Class - DDT).

- ADS Class follows the administrative and technical regulation as defined in “Formula Student 2026 Rules” and the “Formula Student AI 2026 Rules” document, where the “Formula Student AI 2026 Rules” take precedent,
- For DDT class all technical, inspection, static and dynamic regulations are covered by the document “Formula Student AI 2026 Rules” in addition to some changes to the administrative regulations where the FS-AI rules take precedent.

The Formula Student AI 2026 Rules can be found on the Formula Student website.

© 2026 IMechE | 6 | Formula Student

CONCEPT CLASS INTRODUCTION

Teams may enter Concept Class, competing in static events only (Business Plan Presentation, Cost & Manufacturing, Engineering Design and Lap Time Simulation). Concept Class entries are assumed to be focused on ultimately providing an FS Class entry in a future competition year.

Formula Student allows combustion engine vehicles, electric vehicles and alternative fuelled vehicles; it is assumed that Concept Class entries pay full attention to this important FS specific design brief.

A key design choice for entrants is that of powertrain type. Teams must provide detailed understanding of this choice in their conceptual design decisions.

There are several documents required to be submitted prior the event: the documents are those required for FS Class with some exceptions related to the running vehicle. Key Dates for Concept Class submissions can be found on the Formula Student website.

The submissions required prior to the event are:

- Design Concept Specification,
- Engineering Design Report,
- Engineering Design Spec Sheet,
- LTS Input Deck,
- LTS Model Validation Test Plan,
- Business Plan Presentation slide deck,
- Cost Report Documents comprising,
- BOM for Frame and Body only,
- Cost Explanation File,
- Supporting documents for Frame and Body only.

NOTE: The requirement for pre-judging submissions of individual Engineering Design Score Sheet Category presentations may be added. If required, teams will be informed via email and the Key Dates spreadsheet will be updated. We aim to inform teams of this requirement no later than April for a June submission deadline.

Penalties for lateness, non-submission, and poor-quality submission are as per FS Class.

© 2026 IMechE | 7 | Formula Student

### CHANGELOG

Document | Version | Change
Formula Student 2026 Rules | V1.0 | N/A – New Baseline Rules
Rule | Version | Change
A2.2.4 | 1.0 | Removed restriction on reasons to request to reuse chassis
A4.5.3 | 1.0 | Clarified requirements and role of a Faculty Advisor
A4.7.5 | 1.0 | Clarified that registration fees are non-transferable
A4.10 | 1.0 | Moved insurance requirements to own sub-section and clarified
T2.2.2 | 1.0 | Added restriction on concave radii on bodywork
T3.3.3 | 1.0 | Restricted non-metallic alternative materials to composites only for defined areas
T3.4.3 | 1.0 | Clarified rule
T3.4.6 | 1.0 | Added restriction on use of UD fibres in Primary Structure laminates
T3.5.3 | 1.0 | Baseline steel tube rig compliance test added
T3.5.4 | 1.0 | Composite panels for Front Bulkhead and SIS may not use derived material properties
T3.5.7 | 1.0 | Clarified allowable deviations
T3.11.5 | 1.0 | Added restriction on permissible area of cutouts
T3.15.3 | 1.0 | Added minimum clearance between TS and rearmost impact structure
T3.19.2 | 1.0 | Added requirement for test fixture to be intact after IAD test
T3.20.2 | 1.0 | Added requirement for all aerodynamic devices and sensors to be attached rearwards of the AIP
T8.2.1 | 1.0 | Reduced the maximum height of aerodynamic devices
T12.1.2 | 1.0 | Car numbering background colours clarified
EV2.2.1 | 1.0 | Restricted the maximum TS current
EV2.2.2 | 1.0 | Applied maximum current to regenerative systems
EV3.1.1 | 1.0 | Clarified requirements for insulative properties of enclosures
EV5.5.1 | 1.0 | Clarified positioning of TSACs
EV5.5.2 | 1.0 | Clarified that TSACs may not form part of the primary structure
EV5.5.13 | 1.0 | Defined maximum allowable shear and compressive stress for pouch cells
EV5.8.4 | 1.0 | Allowed alternative locations for cell temperature sensors
EV6.1.4 | 1.0 | Added note on good practice for interlock placement
S3.3.3 | 1.0 | Clarified that the changelog should be a separate document

© 2026 IMechE | 8 | Formula Student
S3.3.4 | 1.0 | Clarified that only 1 hard copy of the CRDs is required
S3.4.4 | 1.0 | Added an exception that fasteners should be included in the CCBOM
S3.5.2 | 1.0 | Added a placeholder for the required CCBOM section to be included in the rules
S3.5.3 | 1.0 | Restructured for clarity and reintroduced fasteners to the CCBOM
S4 | 1.0 | Concept class CRD rules removed to refer back to FS Class

© 2026 IMechE | 9 | Formula Student

### ABBREVIATIONS

ADR | Autonomous Design Report | ESF | Electrical System Form
AFV | Alternative Fuel Vehicle | ESO | Electrical System Officer
AIP | Anti-Intrusion Plate | ESOQ | Electrical System Officer Qualification
AIR | Accumulator Isolation Relay | ETC | Electronic Throttle Control
AMI | Autonomous Mission Indicator | EV | Electric Vehicle
AMS | Accumulator Management System | FTO | Fuel Type Order
APPS | Accelerator Pedal Position Sensor | HPI | High Pressure Injection
AS | Autonomous System | HSC | Hybrid System Container
ASB | Autonomous System Brake | HSF | Hybrid System Form
ASF | Autonomous System Form | HV | High Voltage
ASMS | Autonomous System Master Switch | HVD | High Voltage Disconnect
ASR | Autonomous System Responsible | IA | Impact Attenuator
ASRQ | ASR Qualification | IAD | Impact Attenuator Data
ASSI | Autonomous System Status Indicator | IMD | Insulation Monitoring Device
BOM | Bill of Material | LPI | Low Pressure Injection
BOTS | Brake Over-Travel Switch | LV | Low Voltage
BPP | Business Plan Presentation Event | LVMS | Low Voltage Master Switch
BPPV | Business Plan Pitch Video | LVS | Low Voltage System
BSPD | Brake System Plausibility Device | MU | Magazine Uploads
CCBOM | Costed Carbonised Bill of Material | OC | Off-course
CEEF | Cost and Emissions Explanation File | OEM | Original Equipment Manufacturer
CRD | Cost Report Documents | PCB | Printed Circuit Board
CV | Internal Combustion Engine Vehicle | R2D | Ready-to-drive
DC | Driverless Cup | RES | Remote Emergency System
DI | Direct Injection | RMS | Root Mean Square
DNA | Did Not Attempt | SCS | System Critical Signal
DNF | Did Not Finish | SDC | Shutdown Circuit
DOO | Down or Out | SES | Structural Equivalency Spreadsheet
DQ | Disqualified | TMD | Team Member Designation
DSS | Design Spec Sheet | TPS | Throttle Position Sensor
DV | Driverless | TS | Tractive System
EAIR | ESF Add Item Request | TSAC | Tractive System Accumulator Container
EBS | Emergency Brake System | TSAL | Tractive System Active Light
ECU | Electronic Control Unit | TSMP | Tractive System Measuring Point
EDR | Engineering Design Report | TSMS | Tractive System Master Switch
EI | Flexural Rigidity | USS | Unsafe Stop

© 2026 IMechE | 10 | Formula Student

### SECTION A – ADMINISTRATIVE REGULATIONS

A1 | COMPETITION OVERVIEW
A1.1 | Competition Objective
A1.1.1 | The competition challenges teams of university students to conceive, design, fabricate,
| develop and compete with small, formula style, race cars. The envisaged “target
| customer” for these vehicles is an amateur (non-professional) driver.
A1.1.2 | There are three entry classes: FS Class, FS-AI Class and Concept Class
A1.1.3 | Entrants to Concept Class are to be designed based on being able to be manufactured
| and to then compete in FS Class in the immediate subsequent competition year.
A1.2 | Competition Procedure
A1.2.1 | The competition accepts entries for the following vehicle types:
| • Internal Combustion Engine Vehicle (CV),
| • Electric Vehicles (EV),
| • Alternative Fuel Vehicles (AFV),
| • High Voltage Hybrid powertrains are permitted in this vehicle type.
| • Driverless Vehicles (DV).
A1.2.2 | All vehicles must meet the requirements defined in Section T and Section CV, EV or AFV,
| depending on their powertrain type.
A1.2.3 | The competition starts with a series of technical inspections described in Section IN to
| check the vehicle for safety and compliance with the rules.
A1.2.4 | The competition is divided into a series of static and dynamic events described in Sections
| S and D.
A1.2.5 | The maximum achievable points for FS Class are listed in Table 1.
A1.2.6 | The maximum achievable points for Concept Class are listed in Table 2.
A1.2.7 | In either FS Class or FS-AI Class, if there are no finishers in any dynamic events, then no
| Overall Winner award will be given for that class.
A1.2.8 | The CV, EV or AFV team with the most overall points will win the competition.
A1.2.9 | The official language of the competition is English.

© 2026 IMechE | 11 | Formula Student
FS Class | Points

Static Events:

Lap Time Simulation | 20
Business Plan Presentation | 115
Cost and Manufacturing | 115
Engineering Design | 150

Dynamic Events:

Skid Pad | 75
Acceleration | 75
Autocross / Sprint | 100
Efficiency | 100
Endurance | 250
Total Points | 1000

Table 1: Maximum points awarded – FS Class

Concept Class | Points

Static Events:

Lap Time Simulation | 40
Business Plan Presentation | 120
Cost and Manufacturing | 150
Engineering Design | 150
Total Points | 460

Table 2: Maximum points awarded – Concept Class

© 2026 IMechE | 12 | Formula Student
A2 | VEHICLE ELIGIBILITY
A2.1 | Student Competition
A2.1.1 | Vehicles entering the competition must be conceived, designed and maintained by the student team members without direct involvement from professional engineers, racers, machinists or related professionals.
A2.1.2 | The student team may use any information from professionals or from academics, provided this information is given as a discussion of alternatives with their pros and cons.
A2.1.3 | Professionals may not make design decisions or drawings.
A2.1.4 | Students should manufacture and assemble as much of the vehicle as possible.
A2.2 | First Year Vehicles
A2.2.1 | A vehicle must only compete for one competition year, it’s “first year”, counting from the first day onsite at its first competition. Such a vehicle is defined as “new”. A vehicle may not compete in Formula Student class of the same event (e.g. Formula Student UK FS Class) in the following season, even if two events occur within a one-year period.
A2.2.2 | A team may attend a competition with their vehicle as a “non-competitor” if the team were registered for the Competition but have officially withdrawn prior to the event and have written permission from the Competition officials.
| A “non-competitor”’ cannot take part in any official or practice static or dynamic events. Practice scrutineering and technical rule clarifications are allowed, where time permits, priority will be given to registered entrants.
A2.2.3 | To be classified as new, a vehicle must have a newly manufactured chassis, with significant changes in the Primary Structure to its predecessor.
| [DV Only] Driverless Vehicles (DVs) may reuse a previous chassis from any year, but must be fully compliant with the current version of the rules. The Automated Driving System shall be developed for each new competition year.
A2.2.4 | Teams may apply to reuse a previous year’s chassis. • Requests must be submitted via the Formula Student Question Database (FSQD) before the Structural Equivalency Spreadsheet (SES) deadline,
| • Requests will be reviewed by the Chief Judge or Chief Technical Scrutineer, their decision will be final. • If a team is permitted to reuse a previous year’s chassis, this may attract penalty points for the Design Event.

© 2026 IMechE | 13 | Formula Student
A3 | RULES OF CONDUCT
A3.1 | General Officials Authority
A3.1.1 | The officials reserve the right to revise the schedule, date and location of the competition and/or interpret or modify the competition rules at any time and in any manner that is, in their sole judgment, required for safe and efficient operation.
A3.1.2 | All team members are required to cooperate with and follow all instructions from the officials.
A3.1.3 | Official announcements shall be considered part of the rules.
A3.1.4 | All guidelines and clarifications posted in the “Rules and Important Documents” sections on the competition website for the current season including the competition handbook are considered part of the rules. The “Key Dates” document is considered part of the Rules.
A3.2 | Official Instructions
A3.2.1 | Failure of a team member to follow an instruction or command directed specifically to that team or team member will result in 25 penalty points being deducted from the team’s overall score.
A3.3 | Arguments with Officials
A3.3.1 | Argument with, or disobedience to, any official will result in the team being disqualified from the competition.
A3.4 | Unsportsmanlike Conduct
A3.4.1 | In the event of unsportsmanlike conduct, 25 penalty points will be deducted from the team’s overall score. A second violation will result in the team being disqualified from the competition.
A3.5 | Violations of Intent
A3.5.1 | Violation of the intent of a rule will be considered a violation of the rule itself.
A3.5.2 | Any parts, devices or software fragments designed with the intent to violate a rule, will be considered as a violation.
A3.5.3 | While best efforts are made to prevent them, discrepancies between this rule set and other official documents may occur. In the event of this, this rule set will be considered as authoritative and prevail over other documentation.
A3.6 | Questions about the Rules
A3.6.1 | Questions about the rules may be asked to the officials.
A3.6.2 | The frequently asked questions (FAQ) section on the competition website must be checked before submitting a question.
A3.6.3 | The officials will only answer questions that are not already answered in the rules or FAQs or that require a new or novel interpretation.
A3.6.4 | Questions must be submitted to the Formula Student Questions Database (FSQD) which can be accessed here: https://teams.formulastudent.com/FAQ/AskAQuestion

© 2026 IMechE | 14 | Formula Student
A3.6.5 | Clarifications issued in response to questions about the rules may only be valid for one competition year. If you are submitting a question to reconfirm a previous clarification, the ID number of the original question should be referenced in the new question.
A3.6.6 | Clarifications issued by other events may not be valid at Formula Student, if you are entering multiple events ensure you check the legality of your design with all event organisers.
A3.7 | Protests
A3.7.1 | If a team has a question about scoring, judging, policies or any official action it must be brought to the officials’ attention within the announced protest period for an informal preliminary review before a protest can be filed.
A3.7.2 | A team may protest any rule interpretation, score or official action which they feel has caused some actual, non-trivial, harm to their team, or has had a substantive effect on their score.
A3.7.3 | All protests must be filed in writing and presented to the officials by the team leader. In order to have a protest considered, a team must post a 25-point protest bond which will be forfeited if their protest is rejected.
A3.7.4 | Protests concerning any aspect of the competition must be filed within the protest period announced by the competition organisers in the Team Handbook, or within 30 minutes of the scores of the event to which the protest relates being posted. The formal procedure for posting of results will be described in the Team Handbook.
A3.7.5 | The decision of the officials regarding any protest will be in written form and is final.
A3.8 | Advertising Regulations
A3.8.1 | To ensure full compliance with UK and European legislation, teams are not permitted to display any form of tobacco or cigarette advertising on their vehicles or display areas. The organisers also reserve the right to instruct teams to remove or cover any other vehicle or display area markings that may be illegal or likely to cause offence.
A3.9 | Car Covering
A3.9.1 | Covering or obscuring any competing car or any part of a competing car is considered unsportsmanlike conduct. Teams could receive a penalty of up to 50 points for car covering, at the discretion of the Chief Judge.
A3.9.2 | During the entire Competition, except as permitted below, no screen, cover or other obstruction which in any way obscures any part of a car will be allowed at any time in the paddock, garages, pit lane or grid. The following are permitted:
| • A cover over the car in the garage or paddock overnight,
| • A cover over the car in the pit lane or on the grid if it is raining,
| • Covers on the tyres to prevent debris pick-up,
| • Covers over severely damaged cars or components.
A3.9.3 | Any car part stored in front of the car will be considered as an obstruction unless it is stored flat on the ground and does not totally or partially hide the car. Anybody standing

© 2026 IMechE | 15 | Formula Student

in front of the car is considered as an obstruction to the visibility unless they must work on the car. A line of people in front of the car is strictly prohibited.

© 2026 IMechE | 16 | Formula Student
A4 | GENERAL REQUIREMENTS FOR TEAMS & PARTICIPANTS
A4.1 | Teams per University
A4.1.1 | For FS Class and Concept Class a university may register two (2) teams for each class, if
| they are different power-train types (CV, EV or AFV).
| For FS-AI Class a university may enter one (1) ADS and one (1) DDT entry.
A4.1.2 | Notwithstanding A4.1.1, registration for Formula Student in the UK may be restricted to
| one (1) vehicle per class, per university, regardless of powertrain or vehicle type,
| depending on available space.
A4.1.3 | Teams which are formed with members from two or more universities are treated as a
| single team.
A4.2 | Team Members and Participants
A4.2.1 | A team member may only be part of one team, work on one vehicle and take part in
| static and dynamic events for only one team. Any teams found to be in contravention of
| this rule may receive a 25 point penalty.
A4.2.2 | Each team must have one team member identified as the Team Leader. The Team Leader
| is the main contact person for the officials during the registration process and the
| competition.
A4.2.3 | Persons who have previously attended any official event as a judge are not allowed to
| participate as team members.
A4.2.4 | Team members must be enrolled as degree seeking undergraduate or graduate students
| in any university. Team members who have graduated within the seven-month period
| prior to the competition remain eligible to participate.
A4.2.5 | Students seeking a post graduate degree or equivalent are eligible to compete.
A4.2.6 | Team members must be at least 18 years of age.
A4.2.7 | Team members who will drive a competition vehicle at any time during the competition
| must hold a valid, government issued, photographic driver’s licence for passenger cars, or
| a recognised National Sporting Authority (ASN) approved karting or car motorsport
| licence.
A4.2.8 | Drivers who have driven for a professional racing team in a national or international
| series at any time may not drive in any competition event.
| • A “professional racing team” is defined as a team that provides racing cars and
| enables drivers to compete in national or international racing series and employs staff
| in order to achieve this.
A4.2.9 | Students studying at a UK university must be a member of the Institution of Mechanical
| Engineers to compete at Formula Student.
| • International students with a ‘home FS competition’ may be a member of the
| engineering organisation that organises their home event (e.g. we will accept German
| students who are VDI members). If you do not have one of these home events in your
| country: SAE International, SAE Australasia, SAE Brazil, VDI, VDE, or ATA, your team
| must become IMechE members.

© 2026 IMechE | 17 | Formula Student
- Student Affiliate membership is FREE to all Formula Student team members, regardless of discipline. To apply for Student Affiliate Membership:
- Create or login to your Formula Student team account,
- Select ‘Student Affiliate Form’ on the navigation bar,
- Complete the application from and submit your application.
- Team Leaders must ensure that all team members become IMechE members as defined in the Key Dates Document which can be found at:

https://www.imeche.org/events/formula-student/team-information/key-dates

- Membership numbers must be quoted in the Team Member Details section of your account prior to the event.
- Faculty Advisor membership of an engineering institution is optional.
A4.2.10 | Students who became an IMechE affiliate member in a previous competition year do not need to apply again. They must inform membership@imeche.org that they are continuing to compete in Formula Student in this competition year and supply their name and membership number.
A4.3 | [EV ONLY] Electrical System Officer
A4.3.1 | Every participating team must appoint at least one Electrical System Officer (ESO) for the event. The ESO(s) is responsible for all electrical operations during the event.
A4.3.2 | Where multiple ESOs are appointed, the team must clearly identify which ESO is responsible for which activities. Where responsibility is re-allocated, this must be done with the prior agreement of all ESOs involved.
A4.3.3 | The ESO(s) is the only person in the team who may declare the vehicle electrically safe, in order for work to be performed on any system of the vehicle by the team.
A4.3.4 | The ESO(s) must be valid team members, which means that they must have student status, see A4.2.4, A4.2.5 and A4.2.6.
A4.3.5 | The ESO(s) must be contactable by phone at any time during the competition.
A4.3.6 | An ESO must accompany the vehicle whenever it is operated or moved around the competition site.
A4.3.7 | The ESO is not allowed to be a driver, unless a second ESO is named by the team who is not a driver. If the second ESO is also a driver then they cannot compete in the same dynamic event as the first driver, or a third ESO is required.
A4.3.8 | The ESO must be certified or must have received appropriate practical training, whether formal or informal, for working with high voltage systems in automotive vehicles. Details of the training must be provided to the organizers on the ESO/ESA form for approval.
A4.4 | [DV Only] Autonomous System Responsible
A4.4.1 | To operate the AS every participating team must appoint at least one ASR for the competition. This person is responsible for all autonomous operations of the vehicle

© 2026 IMechE | 18 | Formula Student

during the competition, which includes any work on the autonomous system as well as racing and testing.

A4.4.2 | For vehicles with an electric drivetrain the ASR(s) must fulfil A4.3 and therefore replace the ESO. The team may not register additional ESOs.
A4.4.3 | The ASR(s) are the only persons in the team allowed to declare the autonomous system safe, so that work on any system of the vehicle may be performed by the team, or the vehicle may be operated in manual or autonomous mode.
A4.4.4 | The ASR(s) must be a valid team member, which means that they must have student status, see A4.2.4, A4.2.5 and A4.2.6.
A4.4.5 | The ASR(s) must accompany the vehicle whenever it is operated or moved around at the competition site.
A4.4.6 | If only one ASR is named by the team, the ASR may not be a driver.
A4.4.7 | The ASR(s) must be properly qualified to handle the autonomous system and to understand and deal with problems and failures. A bachelor’s degree in computer science, electrical engineering, mechatronics, automation engineering, robotics or similar is a sufficient qualification.
A4.4.8 | All ASRs are required to attend the team briefing as per the official Event Schedule for the live event.
A4.5 | Faculty Advisor
A4.5.1 | Each team must have a Faculty Advisor appointed by the university.
A4.5.2 | The Faculty Advisor must accompany the team to the competition’s live event and will be considered by competition officials to be the official representative of the university, with responsibility for the behaviour and conduct of all team members during the event. The Faculty Advisor is expected to ensure that wherever possible the regulations and their university’s Health and Safety protocols are followed at all times.
A4.5.3 | If the Faculty Advisor is unable to accompany the team at any time during the event they must send a signed letter to the event officials, nominating who is responsible for the behaviour and conduct of all team members in their absence.
A4.5.4 | Faculty Advisors may advise their teams on general engineering and engineering project management theory.
A4.5.5 | Faculty Advisors may not design, build or repair any part of the competition vehicle or directly participate in the development of any documentation or presentation.
A4.6 | [EV ONLY] Electrical System Advisor (ESA)
A4.6.1 | The ESA must be a professionally competent person(s), nominated by the team, who can advise on the electrical and control systems that will be integrated into the vehicle. It is acceptable for the Faculty Advisor to be the ESA if all the requirements below are met.
A4.6.2 | The ESA must supply details of their experience of electrical and/or control systems engineering as employed in the car on the ESO/ESA form for approval by the organisers. It is likely that the ESA will be a Chartered Engineer or someone of equivalent status.

© 2026 IMechE | 19 | Formula Student
A4.6.3 | The ESA must have significant practical experience of the technology that is being
| developed and its implementation into vehicles or other safety critical systems such that
| they are adequately qualified to advise the team on their proposed electrical and control
| system designs. It may be necessary to have more than one ESA to achieve this
| requirement.
A4.6.4 | The ESA must advise the team such that the merits of any relevant engineering solutions
| can be discussed, questioned and approved before being implemented into the final
| vehicle design.
A4.6.5 | The ESA should advise the students on the required training so that they are competent
| to work with the systems on the vehicle.
A4.6.6 | The ESA must review and sign the Electrical System Form to confirm that in principle the
| vehicle has been designed using good engineering practices.
A4.6.7 | The ESA must ensure that the team discusses any unusual aspects of the design with the
| rules committee to reduce the risk of exclusion or significant changes being required to
| pass technical inspection.
A4.6.8 | All EV team members are required to have basic electrical safety training to ensure they
| are aware of the risks and know how to respond in the event of an incident. Details of
| this training should be documented in the ESO/ESA form.
A4.7 | Registration
A4.7.1 | Registration for Formula Student must be completed online via the Competition website.
| Online registration must be performed by the Team Leader and official Faculty Advisor
| connected with the registering university.
A4.7.2 | Registration for Formula Student UK is limited to a fixed number of competing cars. There
| is no limit to how many teams may be on the reserve list. A reserve team will be notified
| when a registration slot becomes available.
A4.7.3 | Registration for Formula Student is via submission of a Design Concept Specification
| document by the date specified in the Key Dates document. There are no exceptions to
| this registration policy.
A4.7.4 | Registration fees must be paid to the Institution of Mechanical Engineers by the deadline
| specified in the Key Dates document.
A4.7.5 | In the event of a team withdrawing from the competition, registration fees are not
| refundable or transferable. In the event that the competition is cancelled entirely by the
| organisers, the option to defer entry fees to a future competition will be offered.
| Depending on the circumstances around the cancellation, a full or partial refund may be
| offered. Changes to the event schedule, dates or venue are pursuant to Rule A3.1.1.
A4.7.6 | FS Class teams may request to change their entry to Concept Class prior to the deadline
| published in the Key Dates document. This will be subject to capacity in Concept Class.
A4.7.7 | FS-AI ADS teams may request to change their entry to DDT prior to the deadline
| published in the Key Dates document. This will be subject to capacity in DDT class.
A4.8 | Team Member Registration Requirements

© 2026 IMechE | 20 | Formula Student
A4.8.1 | Team Leaders must ensure that every participant’s name, including the Faculty Advisors,
| is listed in the Manage Members section of their Team Account. It is the Team Leader’s
| responsibility to ensure that all team members have their own individual accounts. The
| following is also required:
| • Driver’s licence numbers must be listed for participants who intend to drive a
| competition vehicle.
| • IMechE Membership Number (where required by A4.2.9)
| • Emergency Contact Details for each team member and the Faculty Advisor must be
| submitted online by the deadline specified in the Key Dates document.
A4.8.2 | Details of on-site registration requirements for the live event will be communicated via
| the Team Handbook, release date as per Key Dates document.
A4.9 | Newcomer Registration
A4.9.1 | Teams who will be competing in their first season of the FSAE/FS calendar with a running
| vehicle and have not won a major award at a previous competition, and teams that have
| been absent from FSAE/FS for at least 5 years will be eligible for the Newcomer Award.
| Eligible teams should email fs@imeche.org to advise organisers of their Newcomer
| status.
A4.10 | Competition Team Insurance
A4.10.1 | All teams across all classes (Concept, FS, and FS-AI) are required to confirm that adequate
| insurance cover is in place, including, but not limited to, personal accident insurance for
| all drivers and Public Liability Insurance (minimum £15m) for the team. Team Leaders are
| responsible for submitting a copy of the team’s insurance certificate via the competition
| website in accordance with the Key Dates document.
| Declaration that cover is in place must be provided when a place in the competition is
| offered, accepted and payment is due. Teams will not be permitted to participate without
| this confirmation.
| All participants who are not UK residents must provide proof of valid individual health
| insurance for the competition. This must be provided prior to attendance at any live
| event in accordance with the Key Dates document. Participants will not be accredited for
| any live events without evidence of cover.
A4.10.2 | All participants must sign the Motorsport UK liability waiver. This must be completed by
| each participant via their team member account prior to attendance at any live event in
| accordance with the Key Dates document.
A4.11 | Vehicle Shipping
A4.11.1 | Vehicle shipments by commercial carrier must comply with the laws and regulations of
| nations from which, and to which, the car is being sent. Teams are advised to consult with
| their shipping company or freight forwarder to be sure their shipment fully complies with
| all relevant, customs, import/export and aviation shipping requirements.
A4.11.2 | Shipments must be sent with the sending team or university listed as the receiving party.
| Neither the competition organisers nor the competition sites can be listed as the

© 2026 IMechE | 21 | Formula Student

receiving party. The Institution of Mechanical Engineers will not take responsibility for any shipments or any associated charges. Further details on vehicle shipping can be found on the Formula Student website.

© 2026 IMechE | 22 | Formula Student
A5 | DOCUMENTATION & DEADLINES
A5.1 | Required Documents and Forms
A5.1.1 | Several competition critical documents must be submitted prior to the competition live event. Full details of the document names, format, method of submission and deadlines can be found in the Key Dates document published on the Formula Student website.
| NOTE: The Key Dates document is updated frequently so please check that you are working from the most up to date version as published on the website.
A5.1.2 | Where applicable, templates for the required submissions can be found here:
| https://www.imeche.org/events/formula-student/team-information/forms-and- documents (https://www.imeche.org/events/formula-student/team-information/forms-and-documents)
A5.1.3 | Documents submitted in contradiction to the requirements set out in the Key Dates document, including blank document submissions, will be considered as “Not Submitted”.
A5.2 | Submission
A5.2.1 | Uploaded documents can only be viewed by:
| • Registered members on the team list of the university’s Formula Student team account, including Team Leaders, Team Members and Faculty Advisors, • Authorised Judges, Officials and Scrutineers, • IMechE Staff.
A5.2.2 | By submitting documents via the competition website, the team agrees that they may be reproduced and distributed by the officials, in both complete and edited versions, for educational purposes.
A5.2.3 | Documents or videos that are largely incomplete or not readable/viewable will be considered as “Not Submitted”.
A5.2.4 | Team Leaders are responsible for ensuring that all of their team’s submissions are uploaded or sent no later than the published deadline. Account creation for online document submission is explained on the FS website.
A5.2.5 | The format, method of submission, initial deadline and final deadline are all defined in the Key Dates document published here:
| https://www.imeche.org/events/formula-student/team-information/key-dates
A5.2.6 | SES and IAD submissions are reviewed in the order that they are received. Teams are strongly encouraged to submit these well before the submission deadline.
A5.2.7 | All documents submitted online through your Team Account will generate a confirmation email stating the date and time of your upload. This will be sent to your primary team contact, as defined in your registration form.
| • You are strongly advised to print and retain this confirmation email for the final version of each submission,
| • If the primary contact email changes you must inform formulastudent@imeche.org.

© 2026 IMechE | 23 | Formula Student
A5.3 | Late Submission or Non-Submission
A5.3.1 | The penalties for submitting documents later than the initial and final deadlines are
| defined in the Key Dates document on the Formula Student website.
A5.3.2 | Volunteer judges evaluate all the required submissions, it is essential that they have
| enough time to complete their work. There are no exceptions to the document
| submission deadlines and late submissions will incur penalties.
A5.3.3 | Any penalty for late submission or non-submission of documents required for the Static
| Events will be deducted from the related event score, not the overall competition score.
A5.4 | Correction Requests
A5.4.1 | Judge / Official requested resubmissions to documents must be submitted no more than
| 14 days after the request is sent, as per the Key Dates document.
A5.4.2 | Separate requests for different parts within one document or form will be treated
| independently.
A5.4.3 | The document types that may be subject to resubmission requests by Judges / Officials
| are listed in the Key Dates document. Teams have the option to replace any uploaded
| documents with a new file at any time before the “Submission Deadline” or, where
| applicable the “Final Date for Late Submission” in the Key Dates document.
A5.4.4 | Where applicable, between the “Submission Deadline” (document deadline before
| lateness applies) and the “Final Date for Late Submission” replacement documents are
| classified as late submissions and the appropriate lateness penalties will be applied,
| unless you were asked to resubmit by the Judge / Official reviewing your submission.
A5.4.5 | Judges may request additional supporting documentation, such as Failure Mode and
| Effects Analysis (FMEA), to support document submissions.
A5.5 | SES Approval
A5.5.1 | SES for all vehicles (except DDT) must be submitted in line with the competition Key
| Dates document. All SES will be reviewed by Scrutineering and awarded a ‘Approved or
| ‘Failed’ as part of pre-event checks. Teams who have received a ‘Failed’ result will be able
| to correct the SES and resubmit as many times as is needed prior to the resubmission
| deadline specified in the competition Key Dates document. Teams with not be able to
| pass scrutineering and dynamically compete without an approved SES.
A5.6 | Design Concept Specification
A5.6.1 | All teams must submit a Design Concept Specification (DCS) by way of application to
| compete in the 2026 competition. Submission of the DCS is via your Team Account as per
| the Key Dates document.

© 2026 IMechE | 24 | Formula Student
A6 | GENERAL RULES
A6.1 | Removing the Vehicle from the Site
A6.1.1 | Teams who remove their vehicle ([EV ONLY] or tractive system accumulator) from the competition site after the competition has begun will be disqualified from the competition.
A6.2 | Forfeit for Non-Appearance
A6.2.1 | It is the responsibility of each team to be in the right place at the right time.
A6.2.2 | If a team is not present and ready to compete at the scheduled time, they forfeit their attempt at that event.
A6.3 | Team Briefing
A6.3.1 | The team leader and all drivers for a particular day must attend the team briefing for that day as per the official Event Schedule for the live event.
A6.4 | Testing and Work Safety
A6.4.1 | Teams are reminded that cars built according to the Formula Student and Formula SAE rules are not designed or intended for racing or use at high speed, or in confined areas where they might impact with solid objects, including safety barriers.
| Teams are advised to develop and run their vehicles on large, substantially open areas, and to do so only under similar speed and cornering conditions as they would face at official FSAE or FS events.
| • It is further advised that all cars are checked by a Motorsport UK safety scrutineer. Please email fs@imeche.org to arrange this.
| The competition officials disassociate themselves from all activities of the teams besides their own competition live event and associated events.
A6.4.2 | All teams are advised to follow best engineering, manufacturing, machining and health and safety practices and common sense when working on the vehicle and when operating the vehicle, before, during and after a competition.
A6.4.3 | The vehicles must not participate in events not suitable for this type of vehicle like hill climbs, drag races or similar.
A6.4.4 | Teams must never use their vehicles for wheel-to-wheel races.
A6.4.5 | The following listed requirements are considered the minimum for a testing/operating environment to qualify as safe. Following these guidelines does not guarantee safety under all circumstances:
| • Driver wearing full protection gear according to T13.3,
| • Working TSAL, IMD, AMS, ASSI, RES, EBS, APPS, accelerator/brake pedal plausibility check, and ETC plausibility check if applicable,
| • Rules compliant chassis and mounted impact attenuator,
| • No other passenger cars, trucks etc. being parked or driven on the same premises at the same time, unless the areas are clearly separated,

© 2026 IMechE | 25 | Formula Student
- No running under low visibility conditions,
- No running at speeds above typical event speeds,
- No running in areas where crashing into obstacles at the height of the driver’s head is possible, such that parts of the vehicle may pass below an obstacle, but the driver’s head can be trapped between the obstacle and the main hoop for example.
A6.4.6 | The organisers hereby reserve the right to deduct points, or exclude individuals or teams from future competitions, if they act in such a way, at any time, as to actually or potentially bring the Formula Student name into disrepute.
| Teams or individuals associated with them, displaying and/or running their vehicles at any events organised by themselves or others, who use the Formula Student name while doing so, and act irresponsibly or recklessly, may at the organiser’s sole discretion be deemed to have acted in breach of this rule.
A6.5 | Onsite Working Safety
A6.5.1 | Everyone in the dynamic area and everybody working on the vehicle must wear appropriate, closed-toed shoes.
A6.5.2 | Appropriate personal protective equipment must be used.
A6.5.3 | Any operation producing litter or debris, e.g. cutting of carbon fibre, must not be performed in the pits.
A6.5.4 | When jacking up the vehicle, a safe and stable support device rated for the load must be used.
A6.6 | Alcohol, Illegal Drugs and Illegal Material
A6.6.1 | Drivers should not consume alcohol at least 24 hours before any event they are competing in and may be subject to random breathalyser checks.
A6.6.2 | The use of alcohol or any illegal drug is strictly prohibited on the competition site. If any team member is tested with an alcohol level higher than 0.0 % or positive for illegal drugs, they will be immediately disqualified for the rest of the competition. A second team member being found to have an alcohol level higher than 0.0% or positive for illegal drugs will result in the entire team being disqualified immediately.
A6.6.3 | Team members must ensure they will not be impaired in a manner that could compromise safety by any prescription medications and over-the-counter drugs used as directed for medical purposes.
A6.7 | Vehicle Movement
A6.7.1 | Vehicles must not move under their own power anywhere other than on the practice or competition tracks.
A6.7.2 | [EV ONLY] The detachable handle or key of the Tractive System Master Switch (TSMS) must be completely removed and kept by an ESO. The lockout/tagout function of the TSMS, see EV6.2.2, must be used.

© 2026 IMechE | 26 | Formula Student
A6.7.3 | [EV ONLY] The High Voltage Disconnect (HVD), see EV4.8, must be disconnected at all
| times (including taking part in static events) if the vehicle has not passed electrical
| inspection.
A6.7.4 | [DV ONLY] DV vehicles must also have their autonomous system deactivated when being
| moved around the paddock (see T14.6). The detachable handle or key of the
| Autonomous System Master Switch (ASMS) must be completely removed and kept by an
| ASR. The lockout/tagout function of the ASMS, see T14.6.8, must be used.
A6.7.5 | Vehicles must be pushed at a normal walking pace by means of a “push bar”, see T13.1,
| and with a team member in the cockpit wearing the required driver equipment as
| defined in T13.3 except for helmet, arm restraints and balaclava.
A6.7.6 | The team member in the cockpit must have full control of steering and braking.
A6.7.7 | When the push bar is attached to the vehicle, the engine/tractive system must remain
| switched off.
A6.7.8 | Vehicles with wings are required to have two team members walking on either side of the
| vehicle’s front wing whenever the vehicle is being pushed.
A6.7.9 | Any team found ‘running with the car’ may have their tech sticker removed and will have
| their car confiscated and quarantined by the Chief Technical Scrutineer for a minimum of
| one hour. The one hour will start and end at the discretion of the Chief Technical
| Scrutineer.
A6.8 | [CV ONLY] Engine Running
A6.8.1 | Running engines are not allowed in the pits.
A6.8.2 | Engine running and LV hybrid system activation is allowed in the engine test area and in
| the dynamic area, when the following conditions are met:
| • The vehicle must have passed mechanical inspection,
| • The vehicle must be jacked up using a quick jack, see T13.2,
| • A driver, wearing required driver equipment, see T13.3, must be seated in the cockpit,
| • A fire extinguisher must be immediately available,
| • Driven wheels can only remain fitted to the vehicle if they will not rotate,
| • No one is allowed under the vehicle while the engine is running.
A6.8.3 | Cranking engines in the pits is allowed, when the following conditions are met:
| • The vehicle has passed mechanical inspection,
| • The driven axles are securely jacked up,
| • Gearbox is in neutral,
| • All driven wheels are removed,
| • Connectors to all injectors and ignition coils are detached,
| • A fire extinguisher must be placed next to the engine.

© 2026 IMechE | 27 | Formula Student
A6.9 | Fuelling and Oil
A6.9.1 | Fuelling may only take place at the fuel station and must be conducted by officials only.
A6.9.2 | Open fuel containers are not permitted at the competition.
A6.9.3 | Waste fuel and oil should be disposed of at the location specified in the Event Handbook.
A6.10 | [EV ONLY] Working on the Tractive System
A6.10.1 | Activities on the Tractive System (TS), except for the accumulator (see A6.11) must take place in the pit.
A6.10.2 | All activities require the attendance of the ESO. When the LVMS is switched on, the TSAL must be green at all times, if the LVMS is switched off, the ESO is responsible for testing and declaring the vehicle to be safe prior to any further work being carried out.
A6.10.3 | For activities on the inactive TS, the following procedure must be carried out:
| • The vehicle must be barred from anyone not involved in the work, by using barrier tape,
| • The Tractive System Master Switch (TSMS) must be switched off,
| • It must be assured that the TS cannot by restarted by, at a minimum, using the lockout/tag out of the TSMS,
| • A check for zero-potential must be carried out,
| • A sign that declares the vehicle is electrically safe must be installed. The name of the ESO who is supervising the activities must be noted on the sign. This ESO is the only person who may remove the sign and the barrier.
A6.10.4 | In case of measurements on the active TS or activation of the TS for testing purposes, the following steps must be followed:
| • The vehicle must be located in either the EV scrutineering area or one of the permitted “TS Active” zones (see Team Handbook for details),
| • The vehicle must be barred from anyone not involved in the work, by using barrier tape,
| • The vehicle must be jacked up and the driven wheels removed,
| • One team member must be prepared to push a shutdown button at any time,
| • The TS must only be activated for as long as necessary,
| • Appropriate insulated tools and equipment must be used,
| • Safety glasses with side shields and compliant safety gloves must be worn by all participating team members when parts of the TS are exposed,
| • No other work on the vehicle is permitted when the TS is active.
A6.10.5 | If the TSAL is flashing red or malfunctioning, the TS is considered as active.
A6.10.6 | There must be at least one team member present, who is not directly involved in the work, but who could assist in case of an incident.

© 2026 IMechE | 28 | Formula Student
A6.11 | [EV ONLY] Working on Tractive System Accumulators
A6.11.1 | Opening or working on Tractive System Accumulator Containers (TSACs) is only allowed in the provided workplaces in the charging area, see A6.12.
A6.11.2 | All activities require the attendance of an ESO.
A6.11.3 | Whenever the TSACs are opened, the cell segments must be separated with the maintenance plugs, see EV5.4.3.
A6.11.4 | Appropriate insulated tools and equipment must be used.
A6.11.5 | Safety glasses with side shields and compliant safety gloves must be worn by all participating team members.
A6.11.6 | There must be at least one team member present, who is not directly involved in the work conducted on the accumulator, but who could assist in case of an incident.
A6.11.7 | Moving accumulator cells and/or accumulator segment(s) around at the competition site is only permitted if they are inside a completely closed TSAC.
A6.11.8 | Additional safety measures may be included in the Team Handbook.
A6.12 | [EV ONLY] Charging
A6.12.1 | There will be a separated charging area on the competition site. Charging TS accumulators is only allowed inside this area.
A6.12.2 | Accumulators must be removed from the vehicle and placed on the TSAC hand cart, see EV8.1, for charging.
A6.12.3 | The labels required in EV5.3.8 and EV5.3.9 must be visible during charging.
A6.12.4 | No grinding, drilling, etc. is allowed in the charging area.
A6.12.5 | At least one ESO who has knowledge of the charging process must stay with the accumulator(s) during charging.
A6.13 | Team Radios
A6.13.1 | Any team radios must comply with PMR446:
| https://www.ofcom.org.uk/__data/assets/pdf_file/0025/85156/ir_2009_analogue_and_ digita1.pdf (https://www.ofcom.org.uk/__data/assets/pdf_file/0025/85156/ir_2009_analogue_and_digita1.pdf)
A6.13.2 | Operating on any other frequencies, or with transmission powers greater than 0.5W requires a licence from OFCOM.
A6.13.3 | All team telemetry must be transmitted on a 2.4Ghz frequency. Teams must not transmit on a 5Ghz or any other frequency.
A6.14 | Official Event Schedule
A6.14.1 | The master version of the Event Schedule will be posted on the competition website. In the event of any differences between the master version and any version published elsewhere, then the timings published in the master version prevail.

© 2026 IMechE | 29 | Formula Student
A6.15 | Static Event Judging Schedule
A6.15.1 | In respect for the volunteer judges, teams must notify officials of any inability to attend a scheduled judging session by the date and time specified in the Team Handbook. Please refer to Rule S1 for applicable penalties if this is not adhered to.
A6.15.2 | In exceptional circumstances teams may be offered an alternative scheduled time, but this cannot be guaranteed, and teams must make their best efforts to attend at their original allocated judging time and location.
A6.16 | Mandatory Safety Briefings
A6.16.1 | The Event Schedule details the time and location of all mandatory safety briefings. Failure to attend these briefings and receive the allocated wristband will result in that team member being unable to complete their intended role(s).

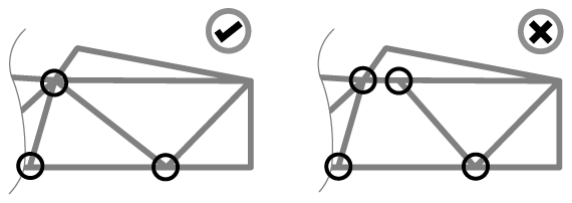
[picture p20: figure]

© 2026 IMechE | 30 | Formula Student
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

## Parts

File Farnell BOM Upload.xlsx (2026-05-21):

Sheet: BOM without SMD
Part number | Footprint | Qty | Voltage measurement |  |  | Duplicate parts across boards | Total Part Quantity | Part Type
FA18X7R1H104KNU00 | FA14_Capacitor:FA18X7R1H104KNU00 | 4 |  |  |  | FA18X7R1H104KNU00 | 25 | Capacitor
FA14X7R1H224KNU00 | FA14_Capacitor:FA14X7R1H224KNU00 | 2 |  |  |  | FA14X7R1H224KNU00 | 4 | Capacitor
FA18X7R1E105KRU00 | FA14_Capacitor:FA18X7R1H104KNU00 | 1 |  |  |  | FA18X7R1E105KRU00 | 5 | Capacitor
400BXC10MEFC10X20 | 400BXC10MEFC10X20:CAPPRD500W60D1025H2200 | 1
FA18C0G1H471JNU00 | FA14_Capacitor:FA18X7R1H104KNU00 | 1
ECE-A1EKS100I | Capacitor_THT:CP_Radial_D5.0mm_P2.50mm | 1 |  |  |  | ECE-A1EKS100I | 5 | Capacitor
STTH1R06 | Diode_THT:D_DO-41_SOD81_P10.16mm_Horizontal | 2
1729128 | Phoenix 1x2 Connector:Phoenix_1x2_1729128 | 2 |  |  |  | 1729128 | 10 | Connector
B3B-XH-A | Connector_JST:JST_XH_B3B-XH-A_1x03_P2.50mm_Vertical | 1 |  |  |  | B3B-XH-A | 11 | Connector
B2B-XH-A | Connector_JST:JST_XH_B2B-XH-A_1x02_P2.50mm_Vertical | 1 |  |  |  | B2B-XH-A | 46 | Connector
7447720122 | Inductor_7447720122:WE-TI_809589 | 1
MCF 0.25W 560K | Resistor_THT:R_Axial_DIN0207_L6.3mm_D2.5mm_P10.16mm_Horizontal | 3
MCF 0.25W 100K | Resistor_THT:R_Axial_DIN0207_L6.3mm_D2.5mm_P10.16mm_Horizontal | 3 |  |  |  | MCF 0.25W 100K | 18 | Resistor
MCF 0.25W 18K | Resistor_THT:R_Axial_DIN0207_L6.3mm_D2.5mm_P10.16mm_Horizontal | 4
MCF 0.25W 4.7K | Resistor_THT:R_Axial_DIN0207_L6.3mm_D2.5mm_P10.16mm_Horizontal | 1
MCF 0.25W 56K | Resistor_THT:R_Axial_DIN0207_L6.3mm_D2.5mm_P10.16mm_Horizontal | 3 |  |  |  | MCF 0.25W 56K | 8 | Resistor
MCF 0.25W 10K | Resistor_THT:R_Axial_DIN0207_L6.3mm_D2.5mm_P10.16mm_Horizontal | 3 |  |  |  | MCF 0.25W 10K | 68 | Resistor
MCF 0.25W 2K7 | Resistor_THT:R_Axial_DIN0207_L6.3mm_D2.5mm_P10.16mm_Horizontal | 1
MCF 0.25W 10K | Resistor_THT:R_Axial_DIN0207_L6.3mm_D2.5mm_P10.16mm_Horizontal | 3
MCF 0.25W 2.2K | Resistor_THT:R_Axial_DIN0207_L6.3mm_D2.5mm_P10.16mm_Horizontal | 3 |  |  |  | MCF 0.25W 2.2K | 4 | Resistor
HCPL-817-000E | Package_DIP:DIP-4_W7.62mm | 3 |  |  |  | HCPL-817-000E | 6 | Optocoupler
MCF 0.25W 1M5 | Resistor_THT:R_Axial_DIN0207_L6.3mm_D2.5mm_P10.16mm_Horizontal | 3
Part Number | Footprint | Qty | Precharge
FA18X7R1E105KRU00 | FA14_Capacitor:FA18X7R1H104KNU00 | 2
FA18X7R1H104KNU00 | FA14_Capacitor:FA18X7R1H104KNU00 | 4
FA14X7R1H225KRU00 | FA14_Capacitor:FA14X7R1H224KNU00 | 3
1N4001 | Diode_THT:D_DO-41_SOD81_P10.16mm_Horizontal | 2 |  |  |  | 1N4001 | 6 | Diode
1N4148 | Diode_THT:D_DO-35_SOD27_P7.62mm_Horizontal | 2 |  |  |  | 1N4148 | 3 | Diode
1729128 | Phoenix 1x2 Connector:Phoenix_1x2_1729128 | 2
B2B-XH-A | Connector_JST:JST_XH_B2B-XH-A_1x02_P2.50mm_Vertical | 1
B6B-XH-A | Connector_JST:JST_XH_B6B-XH-A_1x06_P2.50mm_Vertical | 1 |  |  |  | B6B-XH-A | 3 | Connector
G5Q-1A4-DC12 | Relay_THT:Relay_SPST_Omron-G5Q-1A | 1 |  |  |  | G5Q-1A4-DC12 | 2 | Relay
MPF1212S-1W | MPF1212S-1W:MPF1212S-1W | 1
MCF 0.25W 10K | Resistor_THT:R_Axial_DIN0207_L6.3mm_D2.5mm_P10.16mm_Horizontal | 4
MCF 0.25W 1M | Resistor_THT:R_Axial_DIN0207_L6.3mm_D2.5mm_P10.16mm_Horizontal | 1 |  |  |  | MCF 0.25W 1M | 2 | Resistor
MCF 0.25W 100K | Resistor_THT:R_Axial_DIN0207_L6.3mm_D2.5mm_P10.16mm_Horizontal | 5
MCF 0.25W 27K | Resistor_THT:R_Axial_DIN0207_L6.3mm_D2.5mm_P10.16mm_Horizontal | 1 |  |  |  | MCF 0.25W 27K | 16 | Resistor
MCF 0.5W 56K | Resistor_THT:R_Axial_DIN0411_L9.9mm_D3.6mm_P12.70mm_Horizontal | 4
MCF 0.25W 100R | Resistor_THT:R_Axial_DIN0207_L6.3mm_D2.5mm_P10.16mm_Horizontal | 1 |  |  |  | MCF 0.25W 100R | 10 | Resistor
MCF 0.5W 330K | Resistor_THT:R_Axial_DIN0411_L9.9mm_D3.6mm_P12.70mm_Horizontal | 2
MCF 0.25W 5K6 | Resistor_THT:R_Axial_DIN0207_L6.3mm_D2.5mm_P10.16mm_Horizontal | 2
MCF 0.25W 1.8M | Resistor_THT:R_Axial_DIN0207_L6.3mm_D2.5mm_P10.16mm_Horizontal | 1
MCF 0.25W 2.2K | Resistor_THT:R_Axial_DIN0207_L6.3mm_D2.5mm_P10.16mm_Horizontal | 1
HCPL-817-000E | Package_DIP:DIP-4_W7.62mm | 2
Part Number | Footprint | Qty | Discharge
HCPL-817-000E | Package_DIP:DIP-4_W7.62mm | 1
MCF 0.25W 56K | Resistor_THT:R_Axial_DIN0207_L6.3mm_D2.5mm_P10.16mm_Horizontal | 4
MCF 0.25W 10K | Resistor_THT:R_Axial_DIN0207_L6.3mm_D2.5mm_P10.16mm_Horizontal | 1
B3B-XH-A | Connector_JST:JST_XH_B3B-XH-A_1x03_P2.50mm_Vertical | 1
1729128 | Phoenix 1x2 Connector:Phoenix_1x2_1729128 | 2
B2B-XH-A | Connector_JST:JST_XH_B2B-XH-A_1x02_P2.50mm_Vertical | 1
1N4148 | Diode_THT:D_DO-35_SOD27_P7.62mm_Horizontal | 1
1N4001 | Diode_THT:D_DO-41_SOD81_P10.16mm_Horizontal | 1
FA18X7R1E105KRU00 | FA14_Capacitor:FA18X7R1H104KNU00 | 2
Part Number | Footprint | Qty | Breakout
FA18X7R1H104KNU00 | FA14_Capacitor:FA18X7R1H104KNU00 | 8
ECE-A1EKS100I | Capacitor_THT:CP_Radial_D5.0mm_P2.50mm | 2
RDEC71E226K3P1H03B | RDEC71E:RDEC71E226K3P1H03B | 1
B3B-XH-A | Connector_JST:JST_XH_B3B-XH-A_1x03_P2.50mm_Vertical | 1
B2B-XH-A | Connector_JST:JST_XH_B2B-XH-A_1x02_P2.50mm_Vertical | 1
B3B-XH-A | Connector_JST:JST_XH_B3B-XH-A_1x03_P2.50mm_Vertical | 1
B3B-XH-A | Connector_JST:JST_XH_B3B-XH-A_1x03_P2.50mm_Vertical | 1
B3B-XH-A | Connector_JST:JST_XH_B3B-XH-A_1x03_P2.50mm_Vertical | 1
B3B-XH-A | Connector_JST:JST_XH_B3B-XH-A_1x03_P2.50mm_Vertical | 1
B4B-XH-A | Connector_JST:JST_XH_B4B-XH-A_1x04_P2.50mm_Vertical | 1 |  |  |  | B4B-XH-A | 2 | Connector
B4B-XH-A | Connector_JST:JST_XH_B4B-XH-A_1x04_P2.50mm_Vertical | 1
B2B-XH-A | Connector_JST:JST_XH_B2B-XH-A_1x02_P2.50mm_Vertical | 1
B2B-XH-A | Connector_JST:JST_XH_B2B-XH-A_1x02_P2.50mm_Vertical | 1
B2B-XH-A | Connector_JST:JST_XH_B2B-XH-A_1x02_P2.50mm_Vertical | 1
B3B-XH-A | Connector_JST:JST_XH_B3B-XH-A_1x03_P2.50mm_Vertical | 1
MCF 0.25W 10K | Resistor_THT:R_Axial_DIN0207_L6.3mm_D2.5mm_P10.16mm_Horizontal | 4
CFR25SJT-52A20K | Resistor_THT:R_Axial_DIN0207_L6.3mm_D2.5mm_P10.16mm_Horizontal | 4
MCF 0.25W 100R | Resistor_THT:R_Axial_DIN0207_L6.3mm_D2.5mm_P10.16mm_Horizontal | 3
MCF 0.25W 100K | Resistor_THT:R_Axial_DIN0207_L6.3mm_D2.5mm_P10.16mm_Horizontal | 4
MCF 0.25W 1K | Resistor_THT:R_Axial_DIN0207_L6.3mm_D2.5mm_P10.16mm_Horizontal | 4 |  |  |  | MCF 0.25W 1K | 8 | Resistor
MCF 0.25W 220 | Resistor_THT:R_Axial_DIN0207_L6.3mm_D2.5mm_P10.16mm_Horizontal | 1
MCF 0.25W 120 | Resistor_THT:R_Axial_DIN0207_L6.3mm_D2.5mm_P10.16mm_Horizontal | 1
Part Number | Footprint | Qty | PDU
3557-2 | Kicad_Libraries:FUSE_3557-2 | 11
B2B-XH-A | Connector_JST:JST_XH_B2B-XH-A_1x02_P2.50mm_Vertical | 1
B2B-XH-A | Connector_JST:JST_XH_B2B-XH-A_1x02_P2.50mm_Vertical | 1
B2B-XH-A | Connector_JST:JST_XH_B2B-XH-A_1x02_P2.50mm_Vertical | 1
B2B-XH-A | Connector_JST:JST_XH_B2B-XH-A_1x02_P2.50mm_Vertical | 1
B2B-XH-A | Connector_JST:JST_XH_B2B-XH-A_1x02_P2.50mm_Vertical | 1
B2B-XH-A | Connector_JST:JST_XH_B2B-XH-A_1x02_P2.50mm_Vertical | 1
B2B-XH-A | Connector_JST:JST_XH_B2B-XH-A_1x02_P2.50mm_Vertical | 1
B2B-XH-A | Connector_JST:JST_XH_B2B-XH-A_1x02_P2.50mm_Vertical | 1
B2B-XH-A | Connector_JST:JST_XH_B2B-XH-A_1x02_P2.50mm_Vertical | 1
B2B-XH-A | Connector_JST:JST_XH_B2B-XH-A_1x02_P2.50mm_Vertical | 1
1729128 | Kicad_Libraries:Phoenix_1x2_1729128 | 1
Part Number | Footprint | Qty | LV Shutdown
FA14X7R1H224KNU00 | Kicad_Libraries:FA14X7R1H224KNU00 | 1
FA18X7R1H104KNU00 | Kicad_Libraries:FA18X7R1H104KNU00 | 3
1n4001 | Diode_THT:D_DO-41_SOD81_P10.16mm_Horizontal | 2
B3B-XH-A | Connector_JST:JST_XH_B3B-XH-A_1x03_P2.50mm_Vertical | 1
B6B-XH-A | Connector_JST:JST_XH_B6B-XH-A_1x06_P2.50mm_Vertical | 2
B3B-XH-A | Connector_JST:JST_XH_B3B-XH-A_1x03_P2.50mm_Vertical | 1
B2B-XH-A | Connector_JST:JST_XH_B2B-XH-A_1x02_P2.50mm_Vertical | 1
B2B-XH-A | Connector_JST:JST_XH_B2B-XH-A_1x02_P2.50mm_Vertical | 1
B2B-XH-A | Connector_JST:JST_XH_B2B-XH-A_1x02_P2.50mm_Vertical | 1
B2B-XH-A | Connector_JST:JST_XH_B2B-XH-A_1x02_P2.50mm_Vertical | 1
B2B-XH-A | Connector_JST:JST_XH_B2B-XH-A_1x02_P2.50mm_Vertical | 1
B2B-XH-A | Connector_JST:JST_XH_B2B-XH-A_1x02_P2.50mm_Vertical | 1
B2B-XH-A | Connector_JST:JST_XH_B2B-XH-A_1x02_P2.50mm_Vertical | 1
B2B-XH-A | Connector_JST:JST_XH_B2B-XH-A_1x02_P2.50mm_Vertical | 1
B2B-XH-A | Connector_JST:JST_XH_B2B-XH-A_1x02_P2.50mm_Vertical | 1
B2B-XH-A | Connector_JST:JST_XH_B2B-XH-A_1x02_P2.50mm_Vertical | 1
B2B-XH-A | Connector_JST:JST_XH_B2B-XH-A_1x02_P2.50mm_Vertical | 1
B2B-XH-A | Connector_JST:JST_XH_B2B-XH-A_1x02_P2.50mm_Vertical | 1
B2B-XH-A | Connector_JST:JST_XH_B2B-XH-A_1x02_P2.50mm_Vertical | 1
B2B-XH-A | Connector_JST:JST_XH_B2B-XH-A_1x02_P2.50mm_Vertical | 1
B2B-XH-A | Connector_JST:JST_XH_B2B-XH-A_1x02_P2.50mm_Vertical | 1
B2B-XH-A | Connector_JST:JST_XH_B2B-XH-A_1x02_P2.50mm_Vertical | 1
B2B-XH-A | Connector_JST:JST_XH_B2B-XH-A_1x02_P2.50mm_Vertical | 1
B2B-XH-A | Connector_JST:JST_XH_B2B-XH-A_1x02_P2.50mm_Vertical | 1
B2B-XH-A | Connector_JST:JST_XH_B2B-XH-A_1x02_P2.50mm_Vertical | 1
B2B-XH-A | Connector_JST:JST_XH_B2B-XH-A_1x02_P2.50mm_Vertical | 1
B2B-XH-A | Connector_JST:JST_XH_B2B-XH-A_1x02_P2.50mm_Vertical | 1
G5Q1A4DC12 | Relay_THT:Relay_SPST_Omron-G5Q-1A | 2
LTL-1CHG | Kicad_Libraries:LTL1CHG | 15 |  |  |  | LTL-1CHG | 20 | LED
MCF 0.25W 27K | Resistor_THT:R_Axial_DIN0207_L6.3mm_D2.5mm_P10.16mm_Horizontal | 15
MCF 0.25W 10K | Resistor_THT:R_Axial_DIN0207_L6.3mm_D2.5mm_P10.16mm_Horizontal | 38
MCF 0.25W 100R | Resistor_THT:R_Axial_DIN0207_L6.3mm_D2.5mm_P10.16mm_Horizontal | 6
Part Number | Footprint | Qty | BSPD
FA14X7R1H224KNU00 | Kicad_Libraries:FA14X7R1H224KNU00 | 1
FA18X7R1H104KNU00 | Kicad_Libraries:FA18X7R1H104KNU00 | 6
ECE-A1EKS100I | Capacitor_THT:CP_Radial_D5.0mm_P2.50mm | 2
1N4001 | Diode_THT:D_DO-41_SOD81_P10.16mm_Horizontal | 1
B3B-XH-A | Connector_JST:JST_XH_B3B-XH-A_1x03_P2.50mm_Vertical | 1
B2B-XH-A | Connector_JST:JST_XH_B2B-XH-A_1x02_P2.50mm_Vertical | 2
G5Q-1A4-DC12 | Relay_THT:Relay_SPST_Omron-G5Q-1A | 1
LTL-1CHG | Kicad_Libraries:LTL1CHG | 5
MCF 0.25W 100K | Resistor_THT:R_Axial_DIN0207_L6.3mm_D2.5mm_P10.16mm_Horizontal | 6
MCF 0.25W 1K | Resistor_THT:R_Axial_DIN0207_L6.3mm_D2.5mm_P10.16mm_Horizontal | 4
MCF 0.25W 10K | Resistor_THT:R_Axial_DIN0207_L6.3mm_D2.5mm_P10.16mm_Horizontal | 15
MCF 0.25W 56K | Resistor_THT:R_Axial_DIN0207_L6.3mm_D2.5mm_P10.16mm_Horizontal | 1
MCF 0.25W 1M | Resistor_THT:R_Axial_DIN0207_L6.3mm_D2.5mm_P10.16mm_Horizontal | 1
MCF 0.25W 15K | Resistor_THT:R_Axial_DIN0207_L6.3mm_D2.5mm_P10.16mm_Horizontal | 1
MCF 0.25W 39K | Resistor_THT:R_Axial_DIN0207_L6.3mm_D2.5mm_P10.16mm_Horizontal | 1
3296W-1-103LF | Potentiometer_THT:Potentiometer_Bourns_3296W_Vertical | 3
36-5006-ND | TestPoint:TestPoint_Loop_D2.60mm_Drill1.6mm_Beaded | 6
LM339N | Kicad_Libraries:DIP794W53P254L1930H508Q14N | 2
Part Number | Footprint | Qty | Master
1729128 | Kicad_Libraries:Phoenix_1x2_1729128 | 1
B2B-XH-A | Connector_JST:JST_XH_B2B-XH-A_1x02_P2.50mm_Vertical | 1
B5B-XH-A | Connector_JST:JST_XH_B5B-XH-A_1x05_P2.50mm_Vertical | 1 |  |  |  | B5B-XH-A | 4 | Connector
1729128 | Kicad_Libraries:Phoenix_1x2_1729128 | 1
B2B-XH-A | Connector_JST:JST_XH_B2B-XH-A_1x02_P2.50mm_Vertical | 1
B2B-XH-A | Connector_JST:JST_XH_B2B-XH-A_1x02_P2.50mm_Vertical | 1
B2B-XH-A | Connector_JST:JST_XH_B2B-XH-A_1x02_P2.50mm_Vertical | 1
B2B-XH-A | Connector_JST:JST_XH_B2B-XH-A_1x02_P2.50mm_Vertical | 1
B5B-XH-A | Connector_JST:JST_XH_B5B-XH-A_1x05_P2.50mm_Vertical | 1
1729128 | Kicad_Libraries:Phoenix_1x2_1729128 | 1
B2B-XH-A | Connector_JST:JST_XH_B2B-XH-A_1x02_P2.50mm_Vertical | 1
B5B-XH-A | Connector_JST:JST_XH_B5B-XH-A_1x05_P2.50mm_Vertical | 1
B5B-XH-A | Connector_JST:JST_XH_B5B-XH-A_1x05_P2.50mm_Vertical | 1
CSM2F-8518-L100J01 | ENNOID:CSM2F-8518-L100J01 | 1
Part Number | Footprint | Qty | Slave | X6 | These are being soldered by eurocircuits
53048-0210 | Connector_Molex:Molex_PicoBlade_53048-0210_1x02_P1.25mm_Horizontal | 1 | 6 |  |  | 53048-0210 | 24 | Connector
53048-0210 | Connector_Molex:Molex_PicoBlade_53048-0210_1x02_P1.25mm_Horizontal | 1 | 6
53048-1510 | Connector_Molex:Molex_PicoBlade_53048-1510_1x15_P1.25mm_Horizontal | 2 | 12
53048-0810 | Connector_Molex:Molex_PicoBlade_53048-0810_1x08_P1.25mm_Horizontal | 2 | 12
53048-0210 | Connector_Molex:Molex_PicoBlade_53048-0210_1x02_P1.25mm_Horizontal | 1 | 6
53048-0210 | Connector_Molex:Molex_PicoBlade_53048-0210_1x02_P1.25mm_Horizontal | 1 | 6

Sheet: BOM without duplicates
Part number | Footprint | Qty
400BXC10MEFC10X20 | 400BXC10MEFC10X20:CAPPRD500W60D1025H2200 | 1
FA18C0G1H471JNU00 | FA14_Capacitor:FA18X7R1H104KNU00 | 1
ECE-A1EKS100I | Capacitor_THT:CP_Radial_D5.0mm_P2.50mm | 5
STTH1R06 | Diode_THT:D_DO-41_SOD81_P10.16mm_Horizontal | 2
7447720122 | Inductor_7447720122:WE-TI_809589 | 1
MCF 0.25W 560K | Resistor_THT:R_Axial_DIN0207_L6.3mm_D2.5mm_P10.16mm_Horizontal | 3
MCF 0.25W 18K | Resistor_THT:R_Axial_DIN0207_L6.3mm_D2.5mm_P10.16mm_Horizontal | 4
MCF 0.25W 4.7K | Resistor_THT:R_Axial_DIN0207_L6.3mm_D2.5mm_P10.16mm_Horizontal | 1
MCF 0.25W 2K7 | Resistor_THT:R_Axial_DIN0207_L6.3mm_D2.5mm_P10.16mm_Horizontal | 1
MCF 0.25W 1M5 | Resistor_THT:R_Axial_DIN0207_L6.3mm_D2.5mm_P10.16mm_Horizontal | 3
FA14X7R1H225KRU00 | FA14_Capacitor:FA14X7R1H224KNU00 | 3
MPF1212S-1W | MPF1212S-1W:MPF1212S-1W | 1
MCF 0.5W 56K | Resistor_THT:R_Axial_DIN0411_L9.9mm_D3.6mm_P12.70mm_Horizontal | 4
MCF 0.5W 330K | Resistor_THT:R_Axial_DIN0411_L9.9mm_D3.6mm_P12.70mm_Horizontal | 2
MCF 0.25W 5K6 | Resistor_THT:R_Axial_DIN0207_L6.3mm_D2.5mm_P10.16mm_Horizontal | 2
MCF 0.25W 1.8M | Resistor_THT:R_Axial_DIN0207_L6.3mm_D2.5mm_P10.16mm_Horizontal | 1
RDEC71E226K3P1H03B | RDEC71E:RDEC71E226K3P1H03B | 1
CFR25SJT-52A20K | Resistor_THT:R_Axial_DIN0207_L6.3mm_D2.5mm_P10.16mm_Horizontal | 4
MCF 0.25W 220 | Resistor_THT:R_Axial_DIN0207_L6.3mm_D2.5mm_P10.16mm_Horizontal | 1
MCF 0.25W 120 | Resistor_THT:R_Axial_DIN0207_L6.3mm_D2.5mm_P10.16mm_Horizontal | 1
3557-2 | Kicad_Libraries:FUSE_3557-2 | 11
G5Q1A4DC12 | Relay_THT:Relay_SPST_Omron-G5Q-1A | 2
MCF 0.25W 15K | Resistor_THT:R_Axial_DIN0207_L6.3mm_D2.5mm_P10.16mm_Horizontal | 1
MCF 0.25W 39K | Resistor_THT:R_Axial_DIN0207_L6.3mm_D2.5mm_P10.16mm_Horizontal | 1
3296W-1-103LF | Potentiometer_THT:Potentiometer_Bourns_3296W_Vertical | 3
36-5006-ND | TestPoint:TestPoint_Loop_D2.60mm_Drill1.6mm_Beaded | 6
LM339N | Kicad_Libraries:DIP794W53P254L1930H508Q14N | 2
CSM2F-8518-L100J01 | ENNOID:CSM2F-8518-L100J01 | 1
53048-1510 | Connector_Molex:Molex_PicoBlade_53048-1510_1x15_P1.25mm_Horizontal | 12
53048-0810 | Connector_Molex:Molex_PicoBlade_53048-0810_1x08_P1.25mm_Horizontal | 12
FA18X7R1H104KNU00 | FA14_Capacitor:FA18X7R1H104KNU00 | 25
FA14X7R1H224KNU00 | FA14_Capacitor:FA14X7R1H224KNU00 | 4
FA18X7R1E105KRU00 | FA14_Capacitor:FA18X7R1H104KNU00 | 5
1729128 | Phoenix 1x2 Connector:Phoenix_1x2_1729128 | 10
B3B-XH-A | Connector_JST:JST_XH_B3B-XH-A_1x03_P2.50mm_Vertical | 11
B2B-XH-A | Connector_JST:JST_XH_B2B-XH-A_1x02_P2.50mm_Vertical | 46
MCF 0.25W 100K | Resistor_THT:R_Axial_DIN0207_L6.3mm_D2.5mm_P10.16mm_Horizontal | 18
MCF 0.25W 56K | Resistor_THT:R_Axial_DIN0207_L6.3mm_D2.5mm_P10.16mm_Horizontal | 8
MCF 0.25W 10K | Resistor_THT:R_Axial_DIN0207_L6.3mm_D2.5mm_P10.16mm_Horizontal | 68
MCF 0.25W 2.2K | Resistor_THT:R_Axial_DIN0207_L6.3mm_D2.5mm_P10.16mm_Horizontal | 4
HCPL-817-000E | Package_DIP:DIP-4_W7.62mm | 6
1N4001 | Diode_THT:D_DO-41_SOD81_P10.16mm_Horizontal | 6
1N4148 | Diode_THT:D_DO-35_SOD27_P7.62mm_Horizontal | 3
B6B-XH-A | Connector_JST:JST_XH_B6B-XH-A_1x06_P2.50mm_Vertical | 3
G5Q-1A4-DC12 | Relay_THT:Relay_SPST_Omron-G5Q-1A | 2
MCF 0.25W 1M | Resistor_THT:R_Axial_DIN0207_L6.3mm_D2.5mm_P10.16mm_Horizontal | 2
MCF 0.25W 27K | Resistor_THT:R_Axial_DIN0207_L6.3mm_D2.5mm_P10.16mm_Horizontal | 16
MCF 0.25W 100R | Resistor_THT:R_Axial_DIN0207_L6.3mm_D2.5mm_P10.16mm_Horizontal | 10
B4B-XH-A | Connector_JST:JST_XH_B4B-XH-A_1x04_P2.50mm_Vertical | 2
MCF 0.25W 1K | Resistor_THT:R_Axial_DIN0207_L6.3mm_D2.5mm_P10.16mm_Horizontal | 8
LTL-1CHG | Kicad_Libraries:LTL1CHG | 20
B5B-XH-A | Connector_JST:JST_XH_B5B-XH-A_1x05_P2.50mm_Vertical | 4
53048-0210 | Connector_Molex:Molex_PicoBlade_53048-0210_1x02_P1.25mm_Horizontal | 24

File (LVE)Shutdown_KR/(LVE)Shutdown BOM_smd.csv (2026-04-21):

Reference | Value | Part Number | Datasheet | Footprint | Qty | DNP
Q1,Q2,Q3,Q5 | 2N7002 | 2N7002 | https://www.onsemi.com/pub/Collateral/NDS7002A-D.PDF | Package_TO_SOT_SMD:SOT-23 | 4
U1 | LM7805MPX/NOPB | LM7805MPX/NOPB | https://www.ti.com/lit/gpn/lm7800 | Package_TO_SOT_SMD:SOT-223-3_TabPin2 | 1
U2 | SN74AHC1G02DBVR | SN74AHC1G02DBVR | https://www.ti.com/lit/ds/symlink/sn74ahc1g02.pdf?ts=1738520903275 | Package_TO_SOT_SMD:SOT-23-5 | 1
U6 | MC74HC74ADG | MC74HC74ADG | https://www.onsemi.com/download/data-sheet/pdf/mc74hc74a-d.pdf | Package_SO:SOIC-14_3.9x8.7mm_P1.27mm | 1

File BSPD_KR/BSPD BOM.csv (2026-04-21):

Reference | Value | Part Number | Datasheet | Footprint | Qty | DNP
C4 | 0.22uF | FA14X7R1H224KNU00 | https://www.farnell.com/datasheets/2923220.pdf | Kicad_Libraries:FA14X7R1H224KNU00 | 1
C5,C6,C7,C8,C9,C12 | 0.1uF | FA18X7R1H104KNU00 | https://www.farnell.com/datasheets/2923220.pdf | Kicad_Libraries:FA18X7R1H104KNU00 | 6
C10,C11 | 10uF | ECE-A1EKA100I | https://industrial.panasonic.com/cdbs/www-data/pdf/RDF0000/ABA0000C1050.pdf | Capacitor_THT:CP_Radial_D5.0mm_P2.50mm | 2
D9 | 1N4001 | 1N4001 | http://www.vishay.com/docs/88503/1n4001.pdf | Diode_THT:D_DO-41_SOD81_P10.16mm_Horizontal | 1
J1 | Conn_01x03 | B3B-XH-A | https://www.jst-mfg.com/product/pdf/eng/eXH.pdf | Connector_JST:JST_XH_B3B-XH-A_1x03_P2.50mm_Vertical | 1
J2,J3 | Conn_01x02 | B2B-XH-A | https://www.jst-mfg.com/product/pdf/eng/eXH.pdf | Connector_JST:JST_XH_B2B-XH-A_1x02_P2.50mm_Vertical | 2
K1 | G5Q-1A4-DC12 | G5Q-1A4-DC12 | https://www.mouser.ie/datasheet/2/307/J155_E1-3439950.pdf | Relay_THT:Relay_SPST_Omron-G5Q-1A | 1
LED1,LED2,LED3,LED4,LED5 | LTL-1CHG | LTL-1CHG | https://media.digikey.com/pdf/Data%20Sheets/Lite-On%20PDFs/LTL-1CHG.pdf | Kicad_Libraries:LTL1CHG | 5
Q1,Q3 | 2N7002 | 2N7002 | https://www.onsemi.com/pub/Collateral/NDS7002A-D.PDF | Package_TO_SOT_SMD:SOT-23 | 2
R1,R2,R3,R7,R9,R11 | 100k | MCF 0.25W 100K | https://www.farnell.com/datasheets/3436052.pdf?_gl=1*10s1yq3*_gcl_au*OTY1ODIxNDc3LjE3MzU0MDg2OTk. | Resistor_THT:R_Axial_DIN0207_L6.3mm_D2.5mm_P10.16mm_Horizontal | 6
R4,R5,R6,R19 | 1k | MCF 0.25W 1K | https://www.farnell.com/datasheets/3436052.pdf?_gl=1*1pxxutc*_gcl_au*OTY1ODIxNDc3LjE3MzU0MDg2OTk | Resistor_THT:R_Axial_DIN0207_L6.3mm_D2.5mm_P10.16mm_Horizontal | 4
R8,R10,R12,R13,R14,R15,R16,R17,R18,R22,R25,R26,R27,R28,R29 | 10k | MCF 0.25W 10K | https://www.farnell.com/datasheets/3436052.pdf?_gl=1*j4k0i6*_gcl_au*OTY1ODIxNDc3LjE3MzU0MDg2OTk | Resistor_THT:R_Axial_DIN0207_L6.3mm_D2.5mm_P10.16mm_Horizontal | 15
R20 | 56k | MCF 0.25W 56K | https://www.farnell.com/datasheets/3436052.pdf?_gl=1*6igt67*_gcl_au*OTY1ODIxNDc3LjE3MzU0MDg2OTk. | Resistor_THT:R_Axial_DIN0207_L6.3mm_D2.5mm_P10.16mm_Horizontal | 1
R21 | 1M | MCF 0.25W 1M | http://www.farnell.com/datasheets/3436052.pdf?_gl=1*c0yucm*_gcl_au*MzQwNzkxNTUuMTczODE3NzUyNw | Resistor_THT:R_Axial_DIN0207_L6.3mm_D2.5mm_P10.16mm_Horizontal | 1
R23 | 15k | MCF 0.25W 15K | https://www.farnell.com/datasheets/3436052.pdf?_gl=1*2i638p*_gcl_au*OTY1ODIxNDc3LjE3MzU0MDg2OTk | Resistor_THT:R_Axial_DIN0207_L6.3mm_D2.5mm_P10.16mm_Horizontal | 1
R24 | 39k | MCF 0.25W 39K | http://www.farnell.com/datasheets/3436052.pdf?_gl=1*shqhxd*_gcl_au*MzQwNzkxNTUuMTczODE3NzUyNw | Resistor_THT:R_Axial_DIN0207_L6.3mm_D2.5mm_P10.16mm_Horizontal | 1
RV1,RV2,RV3 | 10k potentiometer | 3296W-1-103LF | https://www.mouser.ie/datasheet/2/54/3296-776415.pdf | Potentiometer_THT:Potentiometer_Bourns_3296W_Vertical | 3
TP1,TP2,TP3,TP4,TP5,TP6 | TestPoint | 36-5006-ND | https://www.keyelco.com/userAssets/file/M65p56.pdf | TestPoint:TestPoint_Loop_D2.60mm_Drill1.6mm_Beaded | 6
U4 | LM7805MPX/NOPB | LM7805MPX/NOPB | https://www.ti.com/lit/gpn/lm7800 | Package_TO_SOT_SMD:SOT-223-3_TabPin2 | 1
U5,U19 | LM339N | LM339N | https://www.ti.com/lit/gpn/lm339 | Kicad_Libraries:DIP794W53P254L1930H508Q14N | 2
U6 | SN74AHC1G02DBVR | SN74AHC1G02DBVR | https://www.ti.com/lit/ds/symlink/sn74ahc1g02.pdf?ts=1738520903275 | Package_TO_SOT_SMD:SOT-23-5 | 1
U9 | SN74LVC1G04DBVT | SN74LVC1G04DBVT | https://www.ti.com/lit/gpn/sn74lvc1g04 | Package_TO_SOT_SMD:SOT-23-5 | 1
U18 | SN74AHCT1G08DBVR | SN74AHCT1G08DBVR | https://www.ti.com/lit/gpn/sn74ahct1g08 | Package_TO_SOT_SMD:SOT-23-5 | 1

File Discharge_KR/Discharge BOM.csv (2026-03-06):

Reference | Value | Part Number | Datasheet | Footprint | Qty | DNP
U2 | HCPL-817-000E | HCPL-817-000E | https://www.mouser.ie/datasheet/2/678/AV02_0265EN_2021_04_26-2935641.pdf | Package_DIP:DIP-4_W7.62mm | 1
U1 | MCP1703AT-3302E/MBVAO | MCP1703AT-3302E/MBVAO | http://ww1.microchip.com/downloads/en/DeviceDoc/20005122B.pdf | Package_TO_SOT_SMD:SOT-89-3 | 1
R8,R9,R10,R11 | 56k | MCF 0.25W 56K | https://www.farnell.com/datasheets/3436052.pdf?_gl=1*1pxxutc*_gcl_au*OTY1ODIxNDc3LjE3MzU0MDg2OTk | Resistor_THT:R_Axial_DIN0207_L6.3mm_D2.5mm_P10.16mm_Horizontal | 4
R3 | 10k | MCF 0.25W 10K | https://www.farnell.com/datasheets/3436052.pdf?_gl=1*1pxxutc*_gcl_au*OTY1ODIxNDc3LjE3MzU0MDg2OTk | Resistor_THT:R_Axial_DIN0207_L6.3mm_D2.5mm_P10.16mm_Horizontal | 1
K1 | DBR71210 | DBR71210 | https://www.mouser.ie/datasheet/2/657/cynergy3_d_pcb_v2-1892244.pdf | DBR71210:DBR71210 | 1
J4 | Conn_01x03 | B3B-XH-A | https://www.jst-mfg.com/product/pdf/eng/eXH.pdf | Connector_JST:JST_XH_B3B-XH-A_1x03_P2.50mm_Vertical | 1
J1,J2,J3 | Conn_01x02 | 1729128,B2B-XH-A | https://www.phoenixcontact.com/en-us/products/printed-circuit-board-terminal-mkdsn-15-2-508-1729128?type=pdf | Connector_JST:JST_XH_B2B-XH-A_1x02_P2.50mm_Vertical,Phoenix 1x2 Connector:Phoenix_1x2_1729128 | 3
D3 | 1N4148 | 1N4148 | https://www.mouser.ie/datasheet/3/101/1/1N914-D.PDF | Diode_THT:D_DO-35_SOD27_P7.62mm_Horizontal | 1
D1 | 1N4001 | 1N4001 | http://www.vishay.com/docs/88503/1n4001.pdf | Diode_THT:D_DO-41_SOD81_P10.16mm_Horizontal | 1
C1,C4 | 1uF | FA18X7R1E105KRU00 | http://www.farnell.com/datasheets/2923220.pdf | FA14_Capacitor:FA18X7R1H104KNU00 | 2

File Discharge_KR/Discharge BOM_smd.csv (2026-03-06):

Reference | Value | Part Number | Datasheet | Footprint | Qty | DNP
U1 | MCP1703AT-3302E/MBVAO | MCP1703AT-3302E/MBVAO | http://ww1.microchip.com/downloads/en/DeviceDoc/20005122B.pdf | Package_TO_SOT_SMD:SOT-89-3 | 1

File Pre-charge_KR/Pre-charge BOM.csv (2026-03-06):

Reference | Value | Part Number | Datasheet | Footprint | Qty | DNP
C1,C4 | 1uF | FA18X7R1E105KRU00 | http://www.farnell.com/datasheets/2923220.pdf | FA14_Capacitor:FA18X7R1H104KNU00 | 2
C2,C6,C10,C14 | 0.1uF | FA18X7R1H104KNU00 | https://www.farnell.com/datasheets/2923220.pdf | FA14_Capacitor:FA18X7R1H104KNU00 | 4
C3,C5,C9 | 2.2uF | FA14X7R1H225KRU00 | http://www.farnell.com/datasheets/2923220.pdf | FA14_Capacitor:FA14X7R1H224KNU00 | 3
D1,D5 | 1N4001 | 1N4001 | https://www.vishay.com/docs/88503/1n4001.pdf | Diode_THT:D_DO-41_SOD81_P10.16mm_Horizontal | 2
D2,D3 | 1N4148 | 1N4148 | https://www.mouser.ie/datasheet/3/101/1/1N914-D.PDF | Diode_THT:D_DO-35_SOD27_P7.62mm_Horizontal | 2
IC2 | TLV1701AIDBVT | TLV1701AIDBVT | http://www.ti.com/lit/gpn/tlv1701 | TLV1701AIDBVT:SOT95P280X145-5N | 1
IC3 | SN74LVC1G11DCKRE4 | SN74LVC1G11DCKRE4 | https://www.ti.com/lit/gpn/sn74lvc1g11 | SOT65:SOT65P210X110-6N | 1
IC4 | SN74LVC1G08IDCKRQ1 | SN74LVC1G08IDCKRQ1 | https://www.arrow.com/en/products/sn74lvc1g08idckrq1/texas-instruments | AND:SOT65P210X110-5N | 1
J1,J3,J4 | Conn_01x02 | 1729128,B6B-XH-A | https://www.jst-mfg.com/product/pdf/eng/eXH.pdf,https://www.phoenixcontact.com/en-us/products/printed-circuit-board-terminal-mkdsn-15-2-508-1729128?type=pdf | Connector_JST:JST_XH_B2B-XH-A_1x02_P2.50mm_Vertical,Phoenix 1x2 Connector:Phoenix_1x2_1729128 | 3
J2 | Conn_01x06 | B6B-XH-A | https://www.jst-mfg.com/product/pdf/eng/eXH.pdf | Connector_JST:JST_XH_B6B-XH-A_1x06_P2.50mm_Vertical | 1
K2 | G5Q-1A4-DC12 | G5Q-1A4-DC12 | https://www.omron.com/ecb/products/pdf/en-g5q.pdf | Relay_THT:Relay_SPST_Omron-G5Q-1A | 1
K3 | 67-1-A-12/2D | 67-1-A-12/2D | http://www.farnell.com/datasheets/3716009.pdf | Pickering Relay:67-1-A-12_2D | 1
PS1 | MPF1212S-1W | MPF1212S-1W | http://www.farnell.com/datasheets/3195163.pdf | MPF1212S-1W:MPF1212S-1W | 1
Q1,Q3 | 2N7002 | 2N7002 | https://www.onsemi.com/pub/Collateral/NDS7002A-D.PDF | Package_TO_SOT_SMD:SOT-23 | 2
R1,R3,R13,R27 | 10k | MCF 0.25W 10K | https://www.farnell.com/datasheets/3436052.pdf?_gl=1*1pxxutc*_gcl_au*OTY1ODIxNDc3LjE3MzU0MDg2OTk | Resistor_THT:R_Axial_DIN0207_L6.3mm_D2.5mm_P10.16mm_Horizontal | 4
R2 | 1M | MCF 0.25W 1M | https://www.farnell.com/datasheets/3436052.pdf?_gl=1*1pxxutc*_gcl_au*OTY1ODIxNDc3LjE3MzU0MDg2OTk | Resistor_THT:R_Axial_DIN0207_L6.3mm_D2.5mm_P10.16mm_Horizontal | 1
R4,R6,R7,R32,R33 | 100k | MCF 0.25W 100K | https://www.farnell.com/datasheets/3436052.pdf?_gl=1*1pxxutc*_gcl_au*OTY1ODIxNDc3LjE3MzU0MDg2OTk | Resistor_THT:R_Axial_DIN0207_L6.3mm_D2.5mm_P10.16mm_Horizontal | 5
R5 | 27k | MCF 0.25W 27K | https://www.farnell.com/datasheets/3436052.pdf?_gl=1*1pxxutc*_gcl_au*OTY1ODIxNDc3LjE3MzU0MDg2OTk | Resistor_THT:R_Axial_DIN0207_L6.3mm_D2.5mm_P10.16mm_Horizontal | 1
R8,R9,R10,R11 | 56k | MCF 0.5W 56K | https://www.farnell.com/datasheets/3436052.pdf?_gl=1*1pxxutc*_gcl_au*OTY1ODIxNDc3LjE3MzU0MDg2OTk | Resistor_THT:R_Axial_DIN0411_L9.9mm_D3.6mm_P12.70mm_Horizontal | 4
R23 | 100 | MCF 0.25W 100R | https://www.farnell.com/datasheets/3436052.pdf?_gl=1*1pxxutc*_gcl_au*OTY1ODIxNDc3LjE3MzU0MDg2OTk | Resistor_THT:R_Axial_DIN0207_L6.3mm_D2.5mm_P10.16mm_Horizontal | 1
R28,R30 | 330k | MCF 0.5W 330K | https://www.farnell.com/datasheets/3436052.pdf?_gl=1*1pxxutc*_gcl_au*OTY1ODIxNDc3LjE3MzU0MDg2OTk | Resistor_THT:R_Axial_DIN0411_L9.9mm_D3.6mm_P12.70mm_Horizontal | 2
R29,R31 | 5.6k | MCF 0.25W 5K6 | https://www.farnell.com/datasheets/3436052.pdf?_gl=1*1pxxutc*_gcl_au*OTY1ODIxNDc3LjE3MzU0MDg2OTk | Resistor_THT:R_Axial_DIN0207_L6.3mm_D2.5mm_P10.16mm_Horizontal | 2
R34 | 1.8M | MCF 0.25W 1.8M | https://www.farnell.com/datasheets/3436052.pdf?_gl=1*1pxxutc*_gcl_au*OTY1ODIxNDc3LjE3MzU0MDg2OTk | Resistor_THT:R_Axial_DIN0207_L6.3mm_D2.5mm_P10.16mm_Horizontal | 1
R35 | 2.2k | MCF 0.25W 2.2k | https://www.farnell.com/datasheets/3436052.pdf?_gl=1*1pxxutc*_gcl_au*OTY1ODIxNDc3LjE3MzU0MDg2OTk | Resistor_THT:R_Axial_DIN0207_L6.3mm_D2.5mm_P10.16mm_Horizontal | 1
U1,U13 | HCPL-817-000E | HCPL-817-000E | https://www.mouser.ie/datasheet/2/678/AV02_0265EN_2021_04_26-2935641.pdf | Package_DIP:DIP-4_W7.62mm | 2
U2 | MCP1703AT-3302E/MBVAO | MCP1703AT-3302E/MBVAO | http://ww1.microchip.com/downloads/en/DeviceDoc/20005122B.pdf | Package_TO_SOT_SMD:SOT-89-3 | 1
U8 | SN74LVC1G04QDBVRQ1 | SN74LVC1G04QDBVRQ1 | https://www.ti.com/lit/ds/symlink/sn74lvc1g04-q1.pdf?ts=1769790994920 | Package_TO_SOT_SMD:SOT-23-5 | 1

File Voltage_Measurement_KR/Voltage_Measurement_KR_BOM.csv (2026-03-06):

Reference | Value | Part number | Datasheet | Footprint | Qty | DNP | Part Number
C1,C2,C7,C9 | 0.1uF | FA18X7R1H104KNU00 | https://www.farnell.com/datasheets/2923220.pdf | FA14_Capacitor:FA18X7R1H104KNU00 | 4
C3,C13 | 0.22uF | FA14X7R1H224KNU00 | https://www.farnell.com/datasheets/2923220.pdf | FA14_Capacitor:FA14X7R1H224KNU00 | 2
C4 | 1uF | FA18X7R1E105KRU00 | https://www.farnell.com/datasheets/2923220.pdf | FA14_Capacitor:FA18X7R1H104KNU00 | 1
C5 | 10uF 400VDC | 400BXC10MEFC10X20 | http://www.farnell.com/datasheets/2321684.pdf | 400BXC10MEFC10X20:CAPPRD500W60D1025H2200 | 1
C6 | 470pF | FA18C0G1H471JNU00 | https://www.farnell.com/datasheets/2923220.pdf | FA14_Capacitor:FA18X7R1H104KNU00 | 1
C12 | 10uF | ECE-A1EKS100I | https://industrial.panasonic.com/cdbs/www-data/pdf/RDF0000/ABA0000C1059.pdf | Capacitor_THT:CP_Radial_D5.0mm_P2.50mm | 1
D3,D5 | STTH1R06 | STTH1R06 | https://www.mouser.ie/datasheet/2/389/stth1r06-1851882.pdf | Diode_THT:D_DO-41_SOD81_P10.16mm_Horizontal | 2
IC1 | MP9488GS-P | MP9488GS-P | https://www.monolithicpower.com/en/documentview/productdocument/index/version/2/document_type/Datasheet/lang/en/sku/MP9488 | MP9488GS-Z:SOIC127P600X175-8N | 1
IC2,IC3,IC4 | TLV1701AIDBVT | TLV1701AIDBVT | http://www.ti.com/lit/gpn/tlv1701 | TLV1701AIDBVT:SOT95P280X145-5N | 3
J1,J2 | Conn_01x02_Phoenix | 1729128 | https://www.phoenixcontact.com/en-us/products/printed-circuit-board-terminal-mkdsn-15-2-508-1729128?type=pdf | Phoenix 1x2 Connector:Phoenix_1x2_1729128 | 2
J3 | Conn_01x03_Pin | B3B-XH-A | https://www.jst-mfg.com/product/pdf/eng/eXH.pdf | Connector_JST:JST_XH_B3B-XH-A_1x03_P2.50mm_Vertical | 1
J4 | Conn_01x02_Pin | B2B-XH-A | https://www.jst-mfg.com/product/pdf/eng/eXH.pdf | Connector_JST:JST_XH_B2B-XH-A_1x02_P2.50mm_Vertical | 1
L1 | 1.2mH | 7447720122 | https://www.we-online.com/components/products/datasheet/7447720122.pdf | Inductor_7447720122:WE-TI_809589 | 1
R1,R9,R13 | 560k | MCF 0.25W 560K | https://www.farnell.com/datasheets/3436052.pdf?_gl=1*1pxxutc*_gcl_au*OTY1ODIxNDc3LjE3MzU0MDg2OTk | Resistor_THT:R_Axial_DIN0207_L6.3mm_D2.5mm_P10.16mm_Horizontal | 3
R2,R3,R18 | 100K | MCF 0.25W 100K | https://www.farnell.com/datasheets/3436052.pdf?_gl=1*1pxxutc*_gcl_au*OTY1ODIxNDc3LjE3MzU0MDg2OTk | Resistor_THT:R_Axial_DIN0207_L6.3mm_D2.5mm_P10.16mm_Horizontal | 3
R4,R6,R10,R14 | 18k | MCF 0.25W 18K | https://www.farnell.com/datasheets/3436052.pdf?_gl=1*1pxxutc*_gcl_au*OTY1ODIxNDc3LjE3MzU0MDg2OTk | Resistor_THT:R_Axial_DIN0207_L6.3mm_D2.5mm_P10.16mm_Horizontal | 4
R5 | 4.7k | MCF 0.25W 4.7K | https://www.farnell.com/datasheets/3436052.pdf?_gl=1*1pxxutc*_gcl_au*OTY1ODIxNDc3LjE3MzU0MDg2OTk | Resistor_THT:R_Axial_DIN0207_L6.3mm_D2.5mm_P10.16mm_Horizontal | 1
R7,R11,R15 | 56k | MCF 0.25W 56K | https://www.farnell.com/datasheets/3436052.pdf?_gl=1*1pxxutc*_gcl_au*OTY1ODIxNDc3LjE3MzU0MDg2OTk | Resistor_THT:R_Axial_DIN0207_L6.3mm_D2.5mm_P10.16mm_Horizontal | 3
R8,R12,R16 | 10k | MCF 0.25W 10K | https://www.farnell.com/datasheets/3436052.pdf?_gl=1*1pxxutc*_gcl_au*OTY1ODIxNDc3LjE3MzU0MDg2OTk | Resistor_THT:R_Axial_DIN0207_L6.3mm_D2.5mm_P10.16mm_Horizontal | 3
R17 | 2.7k | MCF 0.25W 2K7 | https://www.farnell.com/datasheets/3436052.pdf?_gl=1*1pxxutc*_gcl_au*OTY1ODIxNDc3LjE3MzU0MDg2OTk | Resistor_THT:R_Axial_DIN0207_L6.3mm_D2.5mm_P10.16mm_Horizontal | 1
R19,R26,R27 | 10K | MCF 0.25W 10K | https://www.farnell.com/datasheets/3436052.pdf?_gl=1*1pxxutc*_gcl_au*OTY1ODIxNDc3LjE3MzU0MDg2OTk | Resistor_THT:R_Axial_DIN0207_L6.3mm_D2.5mm_P10.16mm_Horizontal | 3
R20,R21,R22 | 2.2K | MCF 0.25W 2.2K | https://www.farnell.com/datasheets/3436052.pdf?_gl=1*1pxxutc*_gcl_au*OTY1ODIxNDc3LjE3MzU0MDg2OTk | Resistor_THT:R_Axial_DIN0207_L6.3mm_D2.5mm_P10.16mm_Horizontal | 3
U1,U2,U3 | HCPL-817-000E | HCPL-817-000E | https://www.mouser.ie/datasheet/2/678/AV02_0265EN_2021_04_26-2935641.pdf | Package_DIP:DIP-4_W7.62mm | 3
U4 | LM7805_SOT223 | LM7805MPX/NOPB | https://www.ti.com/lit/gpn/lm7800 | Package_TO_SOT_SMD:SOT-223-3_TabPin2 | 1
R23,R24,R25 | 1.5M | MCF 0.25W 1.5M | https://www.farnell.com/datasheets/3436052.pdf?_gl=1*1pxxutc*_gcl_au*OTY1ODIxNDc3LjE3MzU0MDg2OTk | Resistor_THT:R_Axial_DIN0207_L6.3mm_D2.5mm_P10.16mm_Horizontal | 3 |  | MCF 0.25W 1M

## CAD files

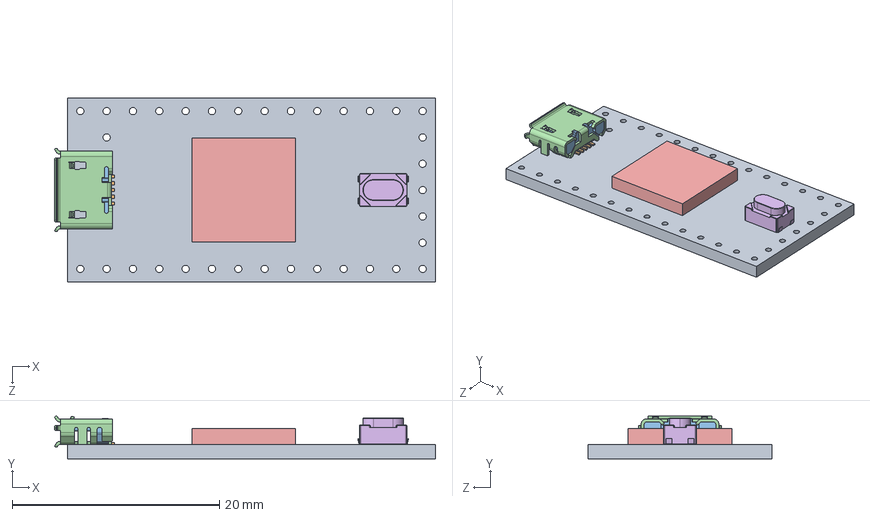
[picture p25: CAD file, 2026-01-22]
Kicad_Libraries/footprints/teensy.pretty-master/Teensy_4.0_Assembly.STEP
36.8 x 4.12 x 17.7 mm
Teensy_4.0_PCB
Micro USB-B Female 5Pin SMD
NXP iMXRT1062
SKRPACE010 v4

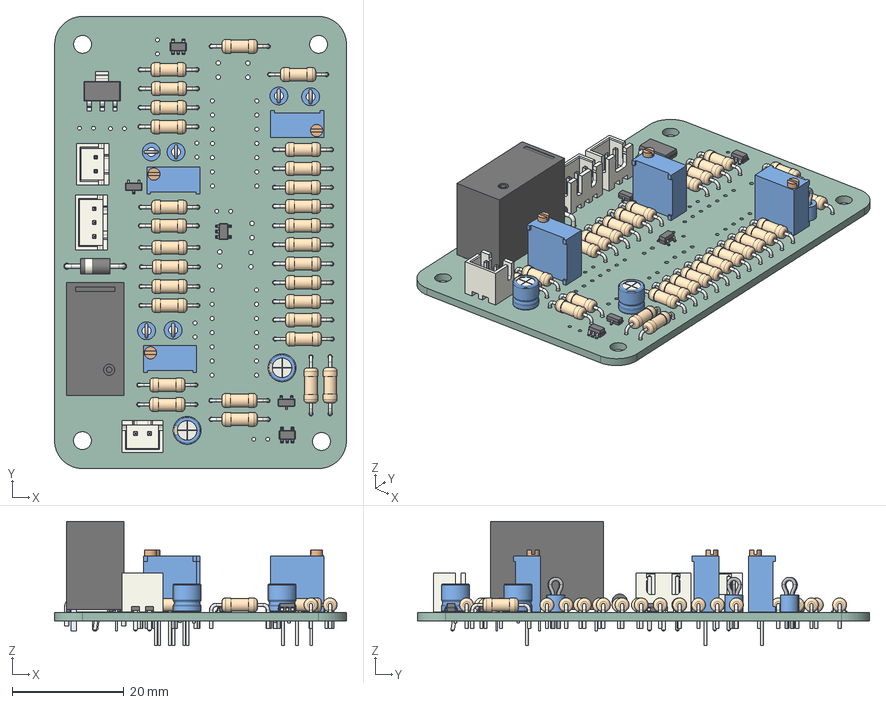
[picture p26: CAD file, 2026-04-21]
BSPD_KR/BSPD KiCAD.step
52.2 x 80.9 x 22.2 mm
R_Axial_DIN0207_L6.3mm_D2.5mm_P10.16mm_Horizontal x 29
JST_XH_B3B-XH-A_1x03_P2.50mm_Vertical
SOT-23-5 x 3
TestPoint_Loop_D2.60mm_Drill1.6mm_Beaded x 6
D_DO-41_SOD81_P10.16mm_Horizontal
G5Q-1A4-DC12
SOT-23 x 2
Potentiometer_Bourns_3296W_Vertical x 3
CP_Radial_D5.0mm_P2.50mm x 2
JST_XH_B2B-XH-A_1x02_P2.50mm_Vertical x 2
SOT-223
BSPD KiCAD_PCB

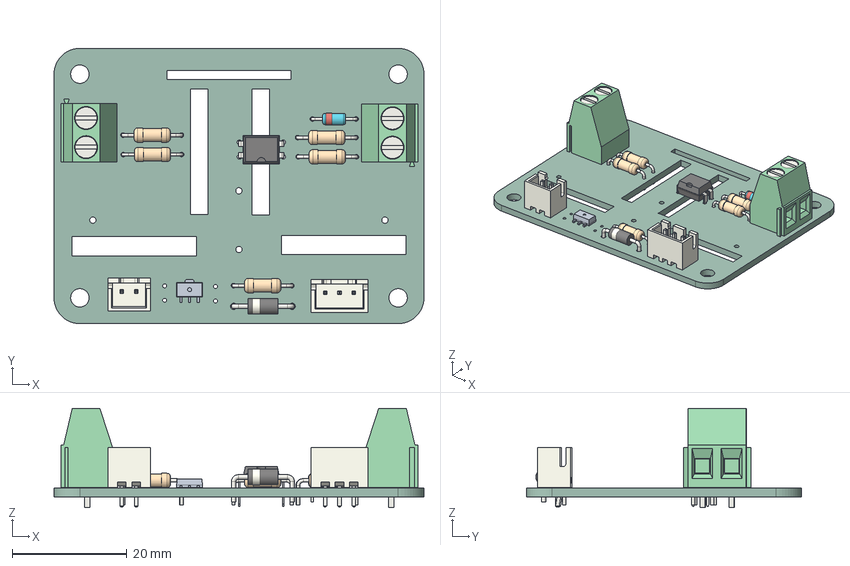
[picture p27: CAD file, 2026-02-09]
Discharge_KR/Discharge KiCAD.step
64.3 x 47.9 x 17.3 mm
D_DO-41_SOD81_P10.16mm_Horizontal
R_Axial_DIN0207_L6.3mm_D2.5mm_P10.16mm_Horizontal x 5
DIP-4_W7.62mm
TerminalBlock_Phoenix_MKDS-1,5-2-5.08_1x02_P5.08mm_Horizontal x 2
Discharge KiCAD 1.8.1
D_DO-35_SOD27_P7.62mm_Horizontal
JST_XH_B3B-XH-A_1x03_P2.50mm_Vertical
JST_XH_B2B-XH-A_1x02_P2.50mm_Vertical
Discharge KiCAD_PCB

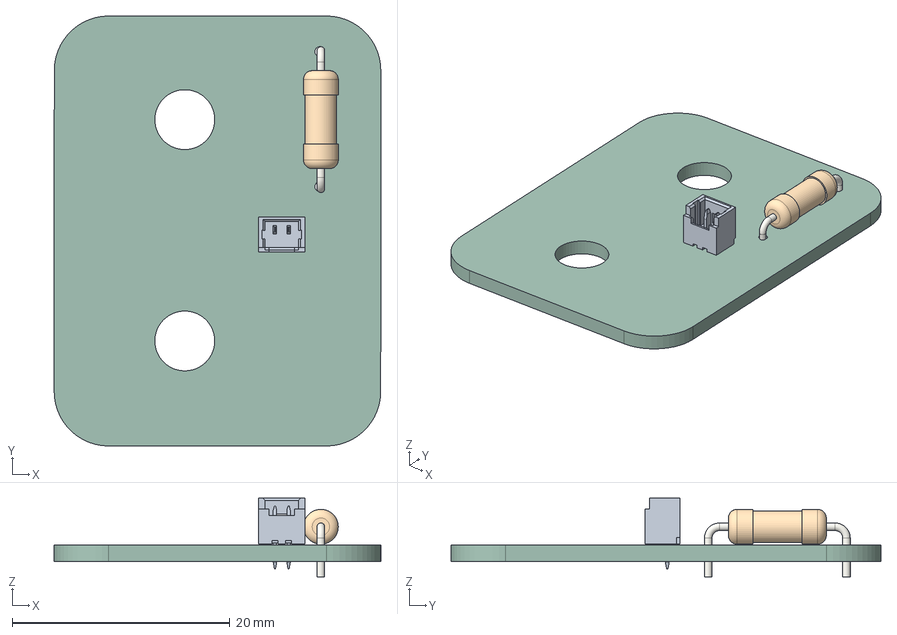
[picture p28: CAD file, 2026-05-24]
ENNOID_BMS/Cell Tap Fuse Board 2x/Cell Tap Fuse Board 2x.step
30.0 x 39.5 x 7.23 mm
R_Axial_DIN0309_L9.0mm_D3.2mm_P12.70mm_Horizontal
Cell Tap Fuse Board 2x_PCB

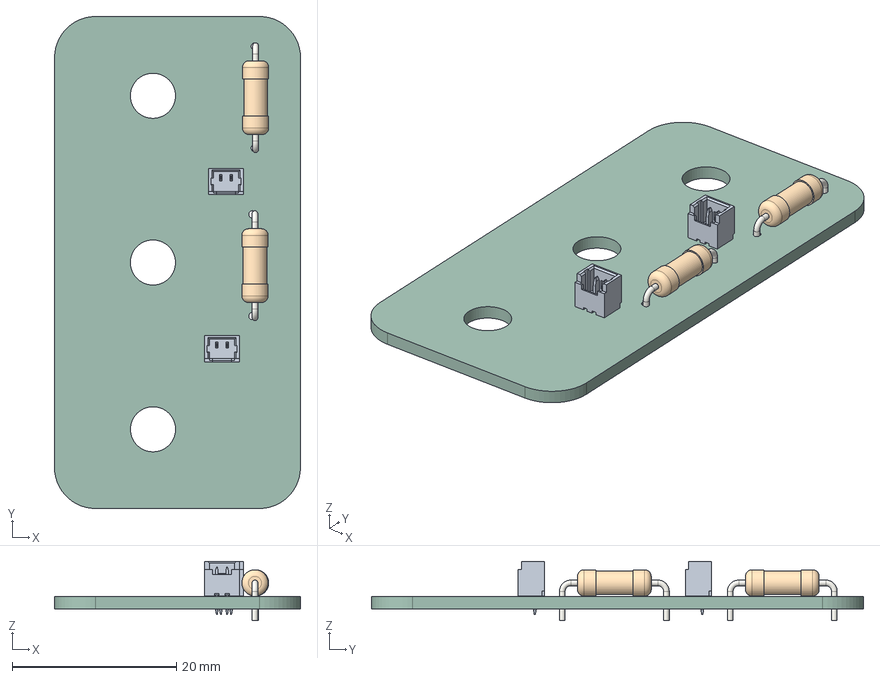
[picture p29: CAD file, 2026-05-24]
ENNOID_BMS/Cell Tap Fuse Board 3x/Cell Tap Fuse Board 3x.step
30.0 x 60.0 x 7.23 mm
R_Axial_DIN0309_L9.0mm_D3.2mm_P12.70mm_Horizontal x 2
Cell Tap Fuse Board 3x_PCB

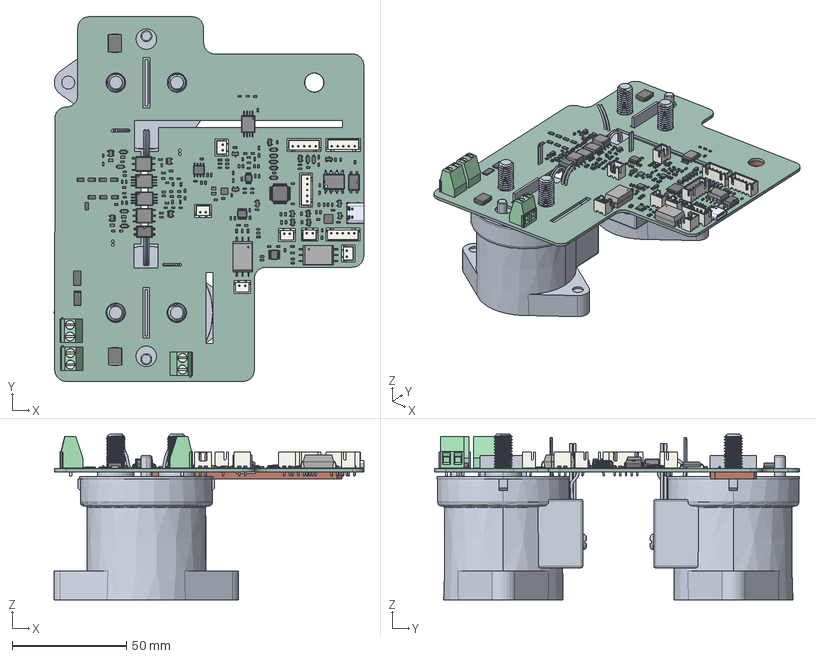
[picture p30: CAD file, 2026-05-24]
ENNOID_BMS/Master/BMS-Master.step
135.3 x 159.4 x 72.4 mm
TerminalBlock_Phoenix_MKDS-1,5-2-5.08_1x02_P5.08mm_Horizontal x 3
C_0805_2012Metric x 6
250-1109_6A x 2
150-2770_6A x 2
C_0603_1608Metric x 59
D_SOD-123 x 11
SOT-23 x 12
UJ20-C-H-G-SMT-1-P16-TR_UJ20-C-H-G-SMT-1-P16-TR
R_2512_6332Metric x 2
JST_XH_B2B-XH-A_1x02_P2.50mm_Vertical x 6
LED_0603_1608Metric x 4
R_0603_1608Metric x 74
AMC1302DWV
Texas_S-PVSON-N10
MSOP-16_3x4.039mm_P0.5mm x 2
c-1-1618002-8-e-3d x 2
R_1206_3216Metric x 8
D_SMC x 2
JST_XH_B5B-XH-A_1x05_P2.50mm_Vertical x 4
SOT-23-5 x 4
QFN-24-1EP_4x4mm_P0.5mm_EP2.7x2.7mm
AMC1301DWV x 2
MSOP-10_3x3mm_P0.5mm
SMDIP-4_W9.53mm_Clearance8mm x 2
LQFP-48_7x7mm_P0.5mm
SOIC-8_3.9x4.9mm_P1.27mm
SMT_2108NL_PUL x 2
ISO1050DUBR--3DModel-STEP-56544
BAS-M-R0002
BMS-Master_PCB

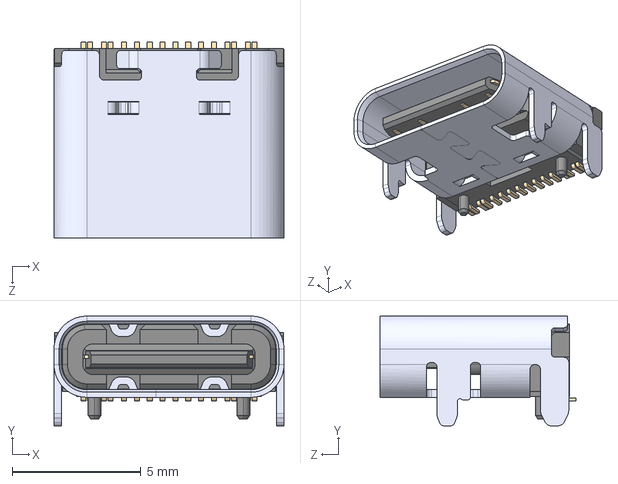
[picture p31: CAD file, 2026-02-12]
ENNOID_BMS/Master/CAD/UJ20-C-H-G-SMT-1-P16-TR.step
8.94 x 4.27 x 7.60 mm

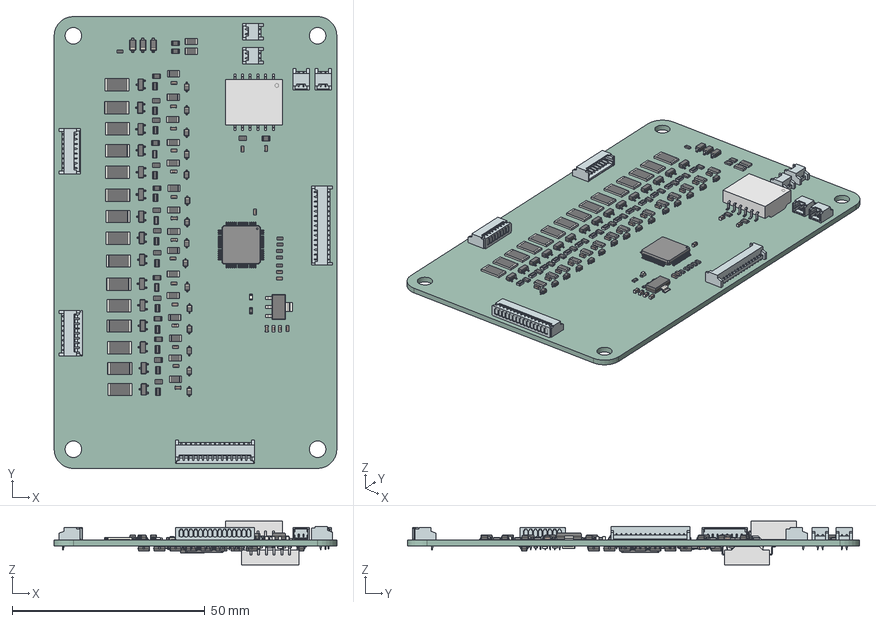
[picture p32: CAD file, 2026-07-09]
ENNOID_BMS/Slave/LTC6812-15W.step
73.4 x 117.4 x 11.4 mm
C_0603_1608Metric x 33
WK73R2ATTD3301F x 30
R_2512_6332Metric x 15
SOT-23 x 30
D_SOD-323 x 15
R_0805_2012Metric x 38
Fuse_1206_3216Metric x 34
D_SOD-123 x 6
R_0603_1608Metric x 29
LTC6812HLWE-1#3ZZPBF x 2
HM2102NL_3D x 2
LED_0603_1608Metric x 2
SOT-223 x 2
LTC6812-15W_PCB

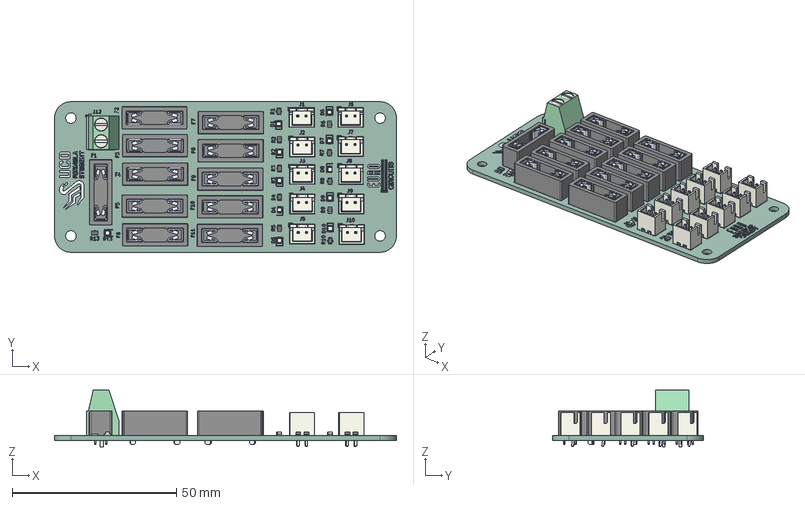
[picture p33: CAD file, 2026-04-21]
PDU_KR/PDU_KR.step
104.2 x 45.9 x 17.3 mm
JST_XH_B2B-XH-A_1x02_P2.50mm_Vertical x 10
LED_0805_2012Metric x 11
R_0805_2012Metric x 11
TerminalBlock_Phoenix_MKDS-1,5-2-5.08_1x02_P5.08mm_Horizontal
PDU_KR_silkscreen
PDU_KR_PCB

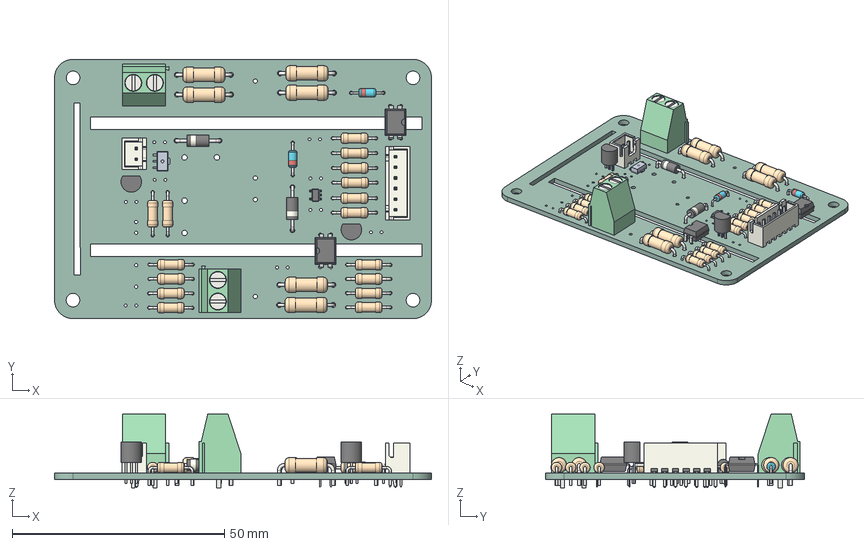
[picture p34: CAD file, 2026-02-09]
Pre-charge_KR/Pre-charge KiCAD.step
88.7 x 61.0 x 17.3 mm
R_Axial_DIN0207_L6.3mm_D2.5mm_P10.16mm_Horizontal x 16
R_Axial_DIN0411_L9.9mm_D3.6mm_P12.70mm_Horizontal x 6
D_DO-35_SOD27_P7.62mm_Horizontal x 2
D_DO-41_SOD81_P10.16mm_Horizontal x 2
TerminalBlock_Phoenix_MKDS-1,5-2-5.08_1x02_P5.08mm_Horizontal x 2
Pre-charge KiCAD 1.18.1
DIP-4_W7.62mm x 2
TO-92_Inline x 2
JST_XH_B2B-XH-A_1x02_P2.50mm_Vertical
SOT-23-5
JST_XH_B6B-XH-A_1x06_P2.50mm_Vertical
Pre-charge KiCAD_PCB

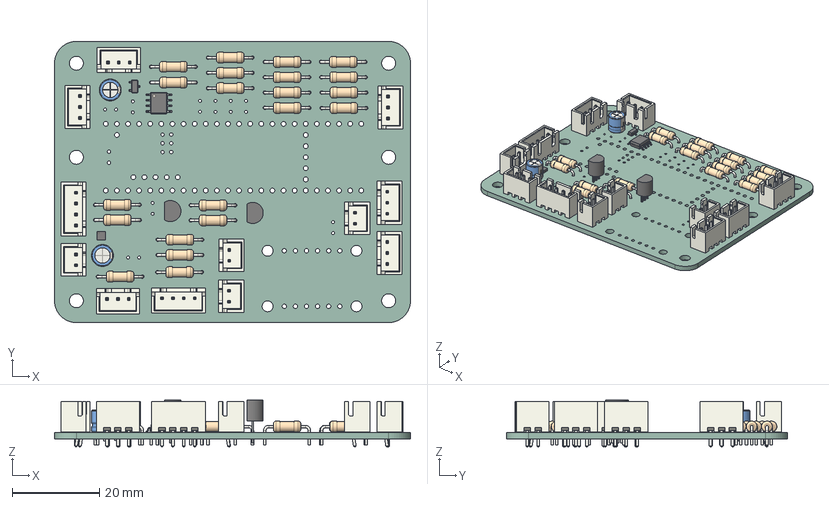
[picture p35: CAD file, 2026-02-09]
Teensy 4.1 Breakout Board/Breakout.step
81.4 x 64.3 x 10.7 mm
R_Axial_DIN0207_L6.3mm_D2.5mm_P10.16mm_Horizontal x 21
TO-92_Inline x 2
JST_XH_B3B-XH-A_1x03_P2.50mm_Vertical x 6
JST_XH_B4B-XH-A_1x04_P2.50mm_Vertical x 2
SOIC-8_3.9x4.9mm_P1.27mm
WSON-8-1EP_2x2mm_P0.5mm_EP0.9x1.6mm
JST_XH_B2B-XH-A_1x02_P2.50mm_Vertical x 4
SOT-23
CP_Radial_D5.0mm_P2.50mm x 2
Breakout_PCB

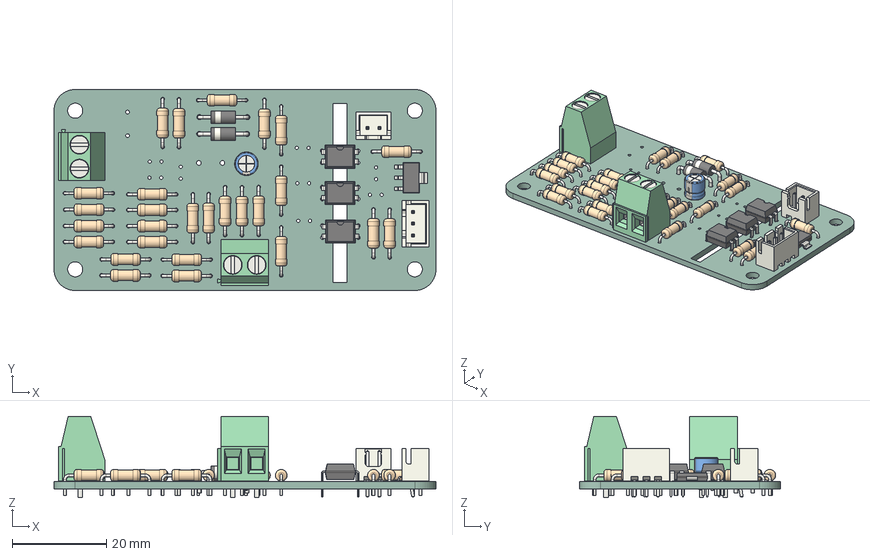
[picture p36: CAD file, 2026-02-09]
Voltage_Measurement_KR/Voltage_Measurement_KR.step
81.2 x 42.7 x 17.3 mm
R_Axial_DIN0207_L6.3mm_D2.5mm_P10.16mm_Horizontal x 27
JST_XH_B2B-XH-A_1x02_P2.50mm_Vertical
D_DO-41_SOD81_P10.16mm_Horizontal x 2
DIP-4_W7.62mm x 3
TerminalBlock_Phoenix_MKDS-1,5-2-5.08_1x02_P5.08mm_Horizontal x 2
CP_Radial_D5.0mm_P2.50mm
SOT-223
JST_XH_B3B-XH-A_1x03_P2.50mm_Vertical
Voltage_Measurement_KR_PCB

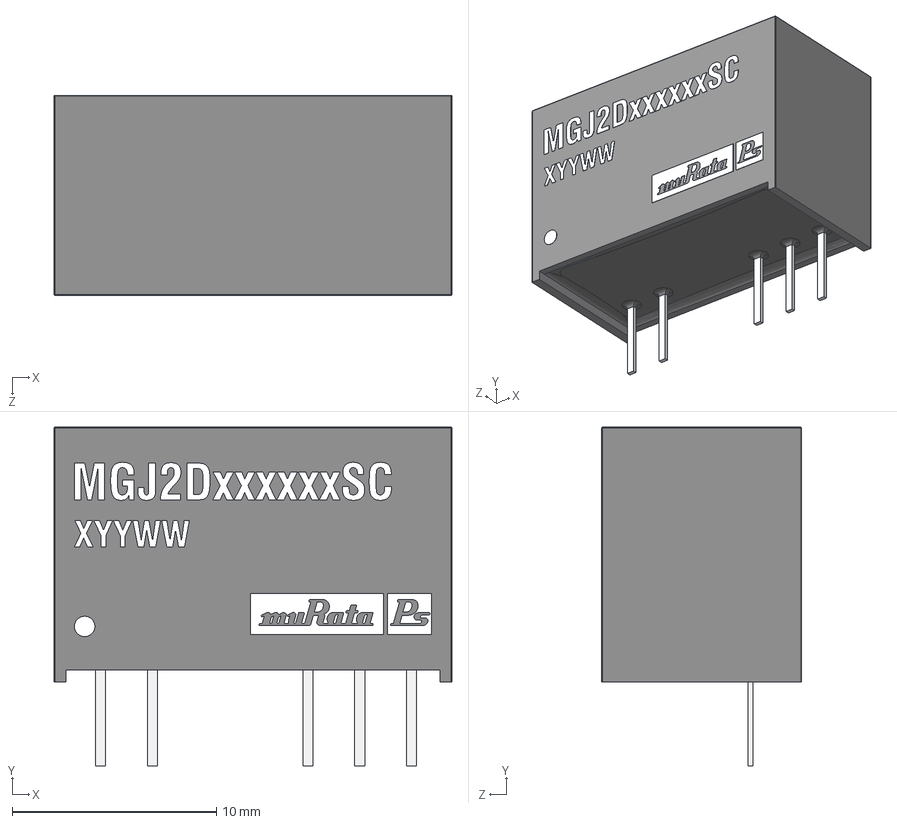
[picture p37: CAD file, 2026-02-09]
ENNOID_BMS/Master/CAD/MGJ2.step
19.5 x 16.6 x 9.82 mm

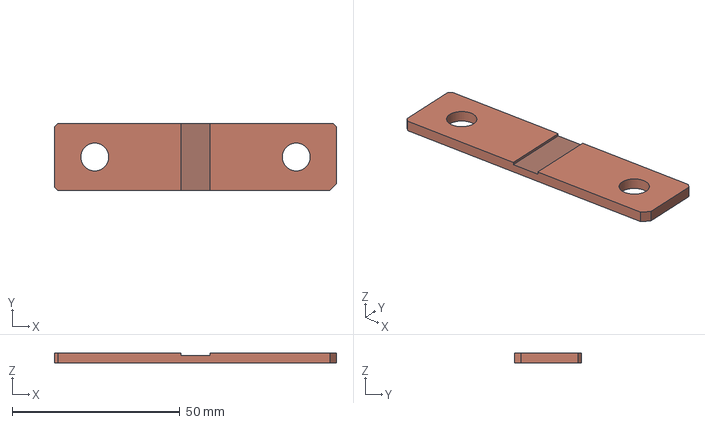
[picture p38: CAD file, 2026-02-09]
ENNOID_BMS/Master/CAD/BAS-M-R0002.step
84.0 x 20.0 x 3.00 mm

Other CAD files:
ENNOID_BMS/Master/CAD/DM3AT-SF-PEJM5.stp
ENNOID_BMS/Master/CAD/AMC1301.step
ENNOID_BMS/Master/CAD/soic_8_66x95_p254.step
ENNOID_BMS/Master/CAD/Spade.step
ENNOID_BMS/Master/CAD/1051330001.stp
ENNOID_BMS/Master/CAD/70543-0001.stp
ENNOID_BMS/Master/CAD/705430004.stp
ENNOID_BMS/Master/CAD/ACM4520.fcstd
ENNOID_BMS/Master/CAD/ACM4520.step
ENNOID_BMS/Master/CAD/AMC1301.fcstd
ENNOID_BMS/Master/CAD/COMPOUND.CATPart
ENNOID_BMS/Master/CAD/COMPOUND_1.CATPart
ENNOID_BMS/Master/CAD/CONN 2X8.step
ENNOID_BMS/Master/CAD/CONN 2x8.fcstd
ENNOID_BMS/Master/CAD/DIP4-OP9.STEP
ENNOID_BMS/Master/CAD/HM2108NL.CATPart
ENNOID_BMS/Master/CAD/Keep_OUT.fcstd
ENNOID_BMS/Master/CAD/Kepp_OUT.dxf
ENNOID_BMS/Master/CAD/SOLID.CATPart
ENNOID_BMS/Master/CAD/SOLID_1.CATPart
ENNOID_BMS/Master/CAD/SOLID_10.CATPart
ENNOID_BMS/Master/CAD/SOLID_11.CATPart
ENNOID_BMS/Master/CAD/SOLID_12.CATPart
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

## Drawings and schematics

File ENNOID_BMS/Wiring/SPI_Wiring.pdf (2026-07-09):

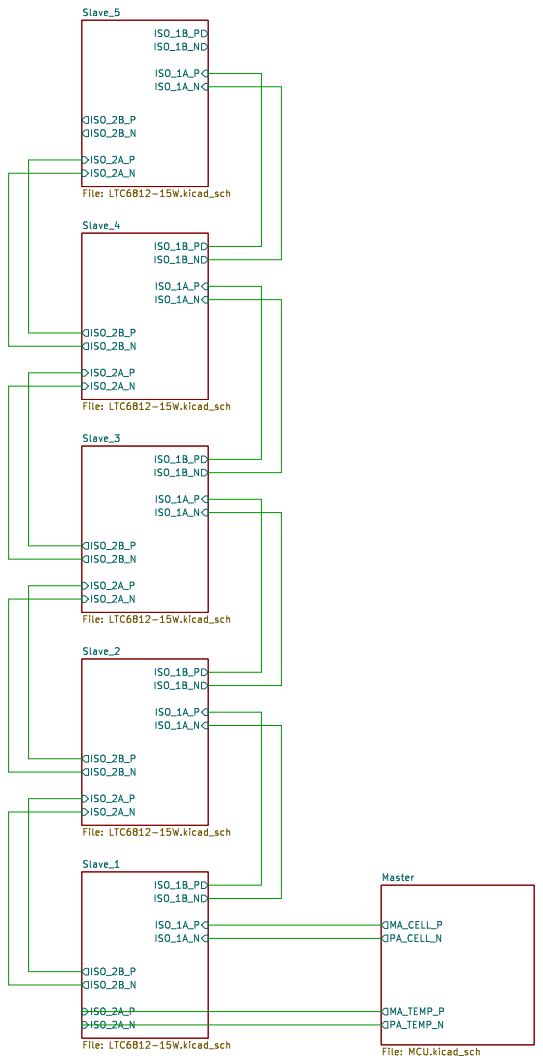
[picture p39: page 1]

Id: 1/82 Title: File: Wiring.kicad_sch Sheet: /

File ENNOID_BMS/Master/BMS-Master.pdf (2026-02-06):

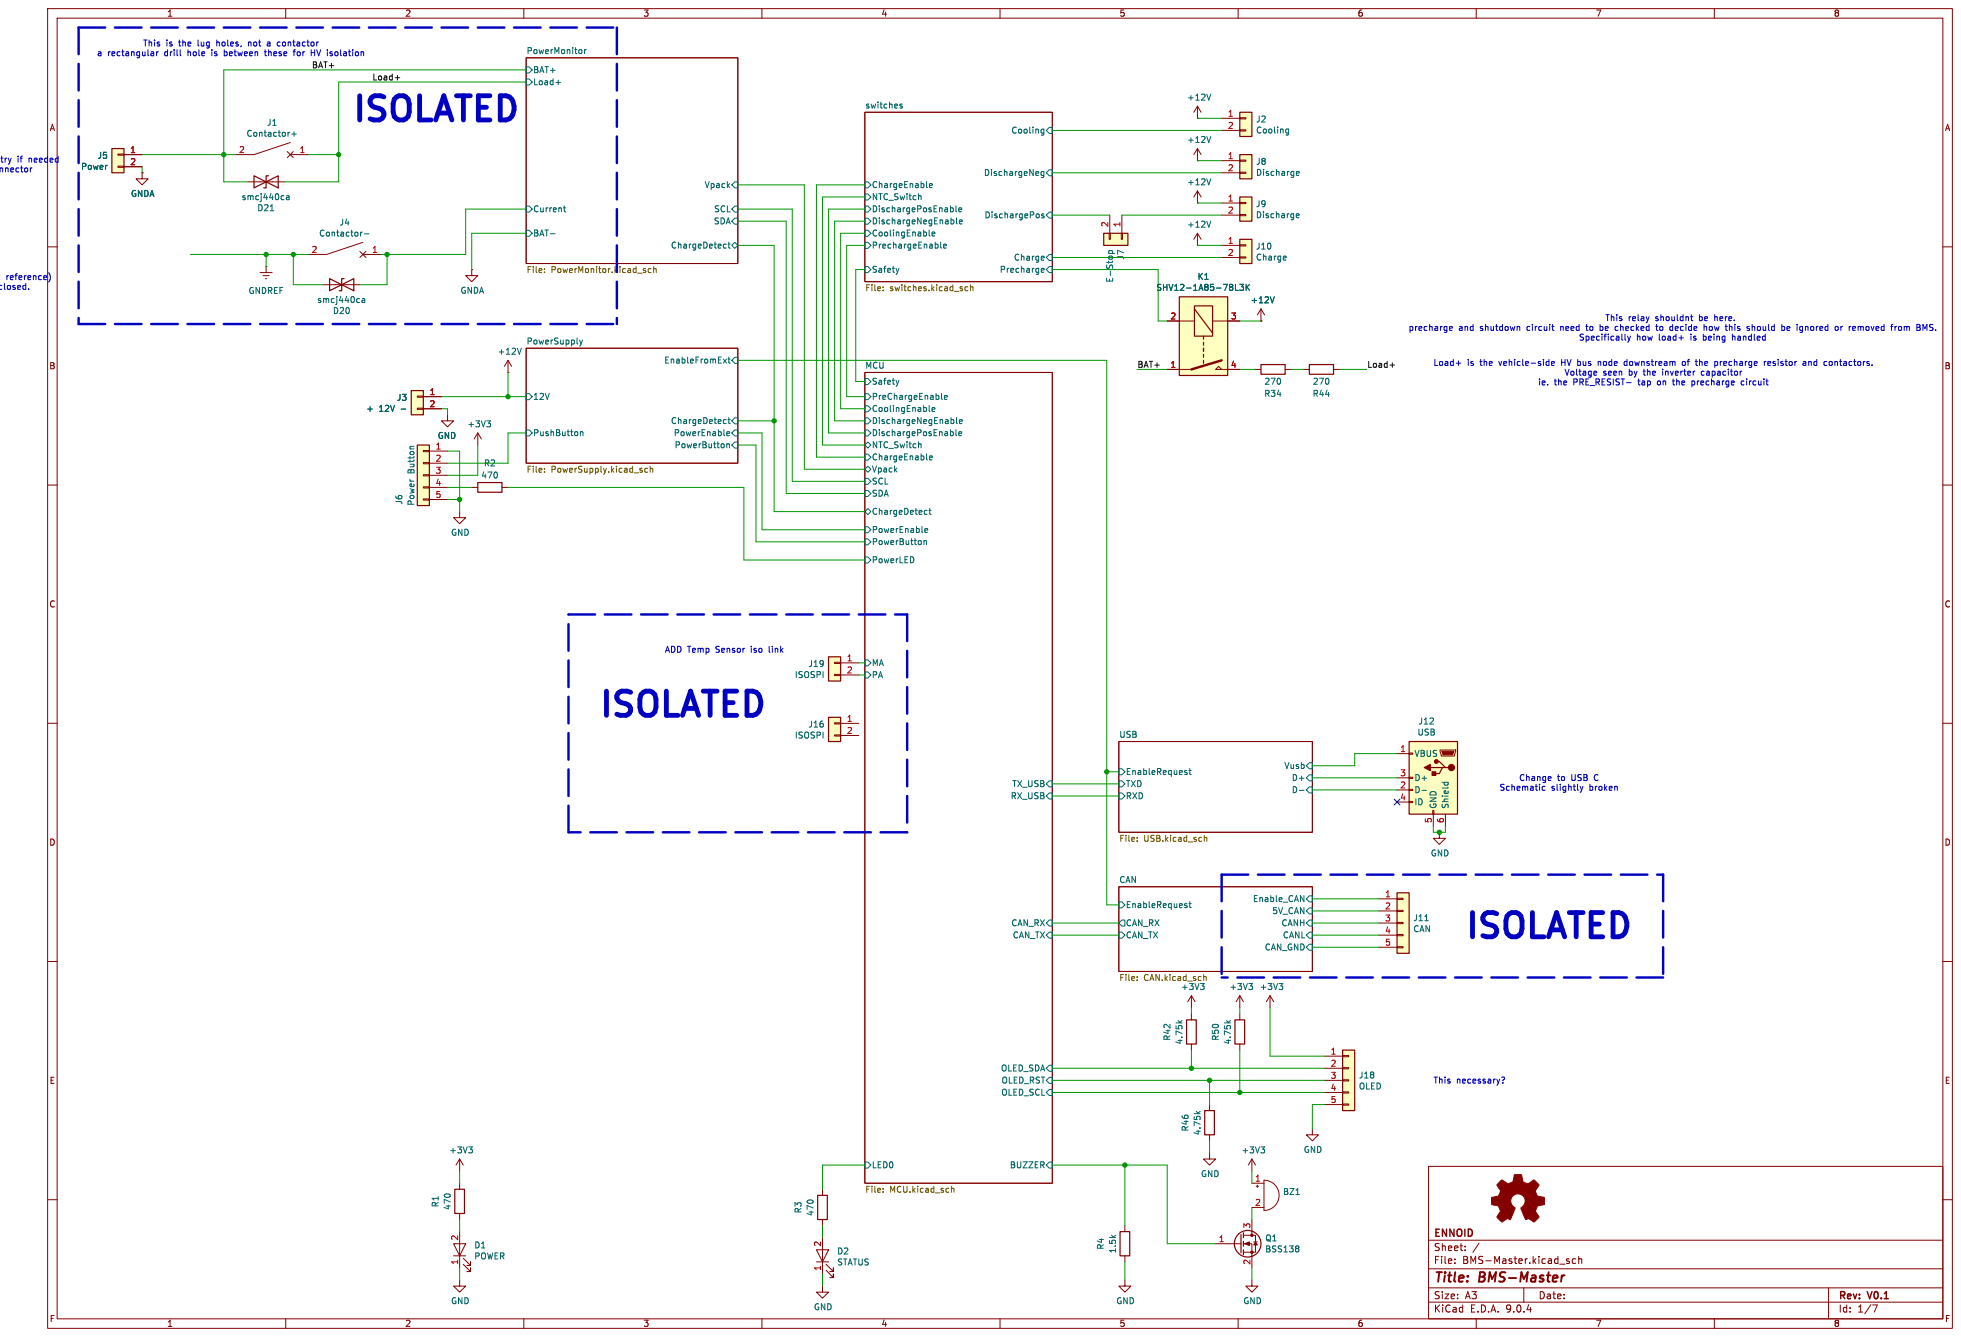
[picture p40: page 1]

1 J7 E-Stop +12V
switches File: switches.kicad_sch ChargeDetect PowerEnable PowerButton PowerLED

ADD Temp Sensor iso link ISOLATED

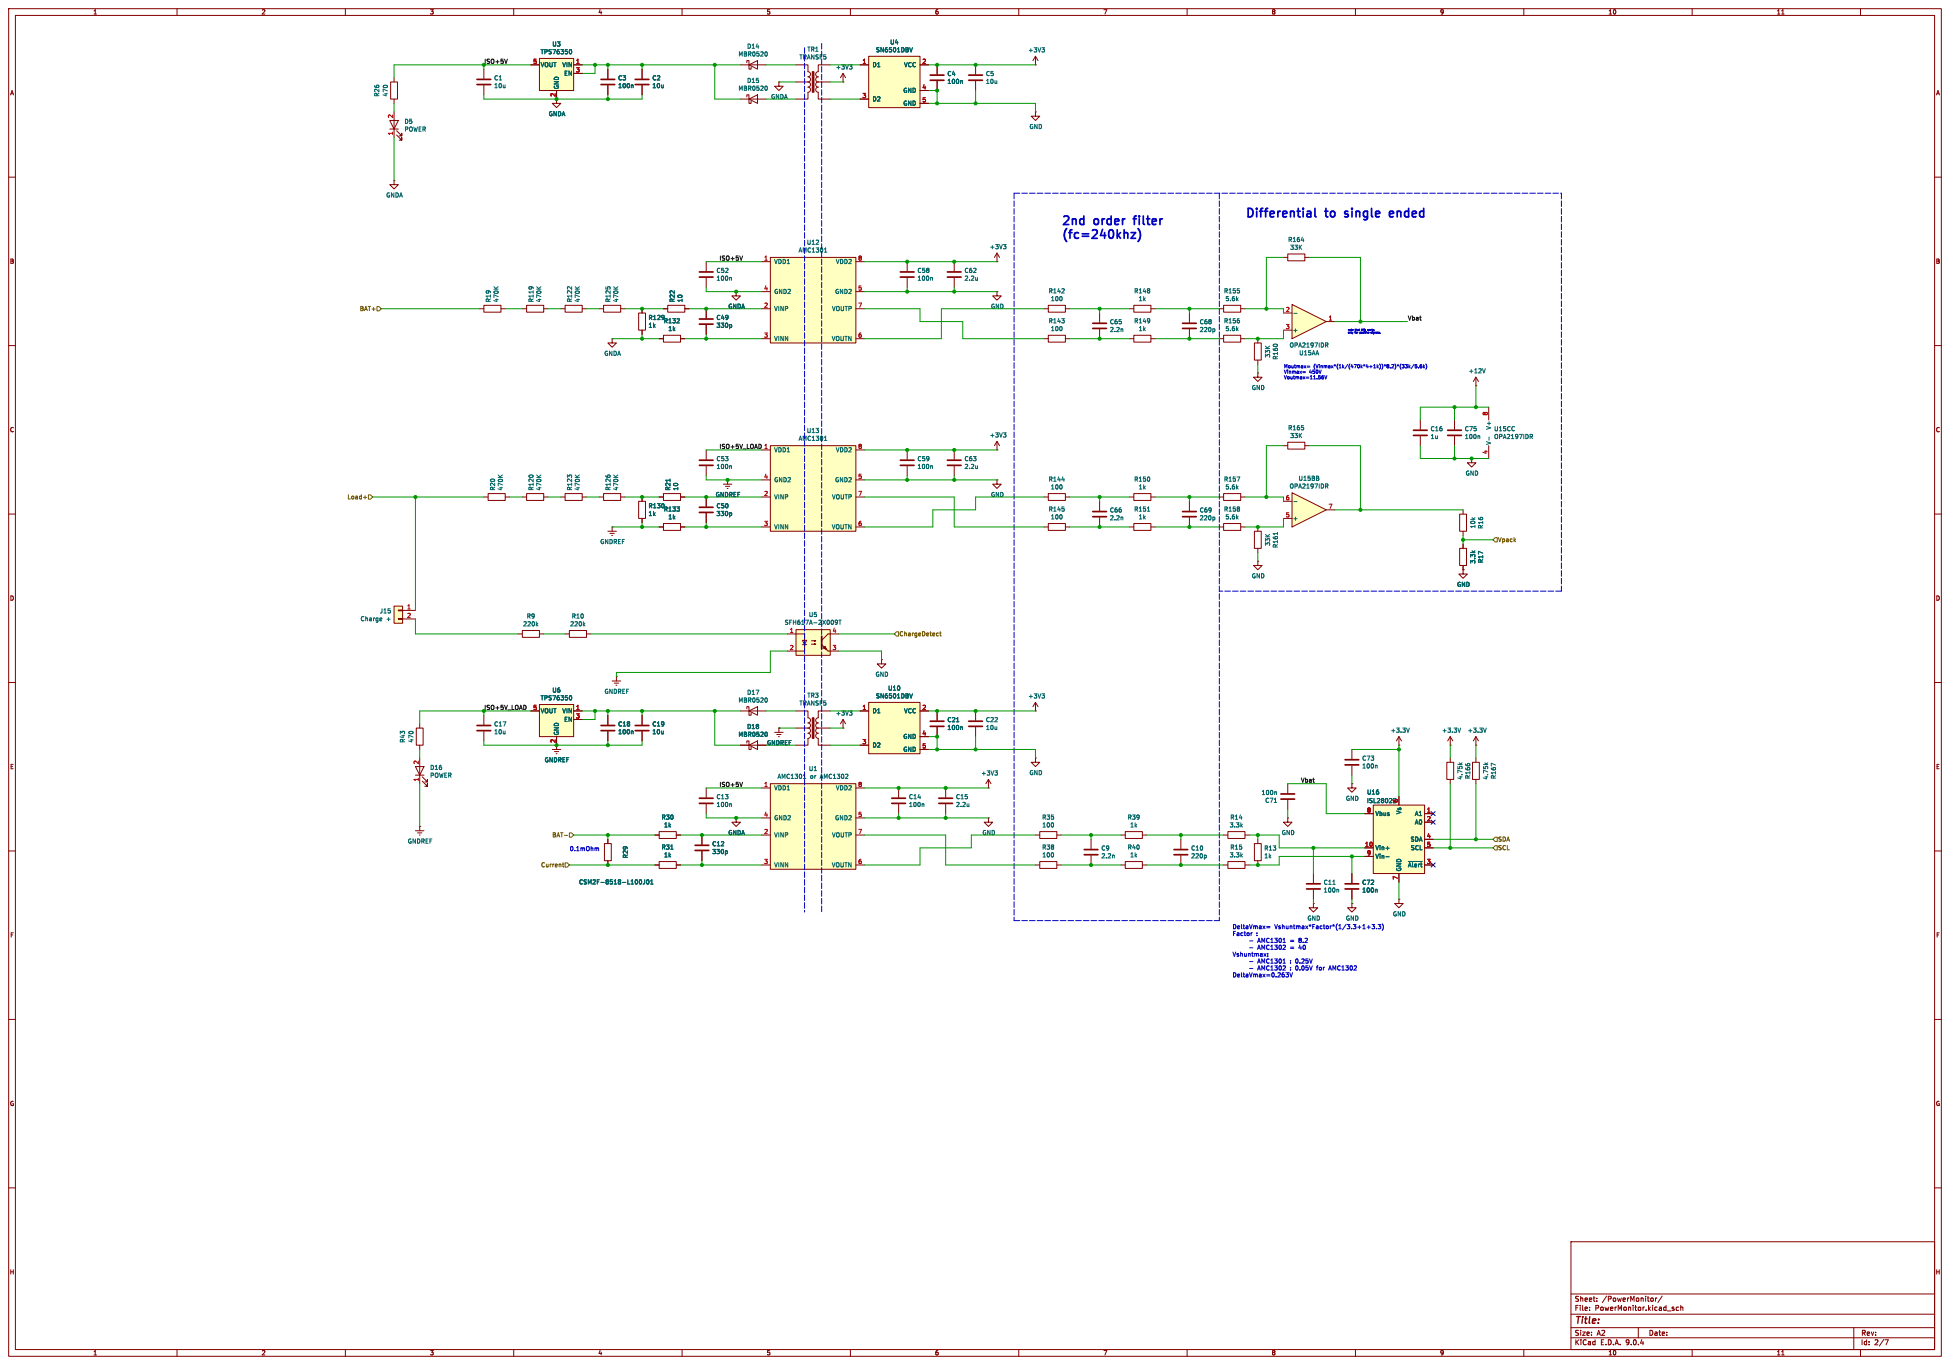
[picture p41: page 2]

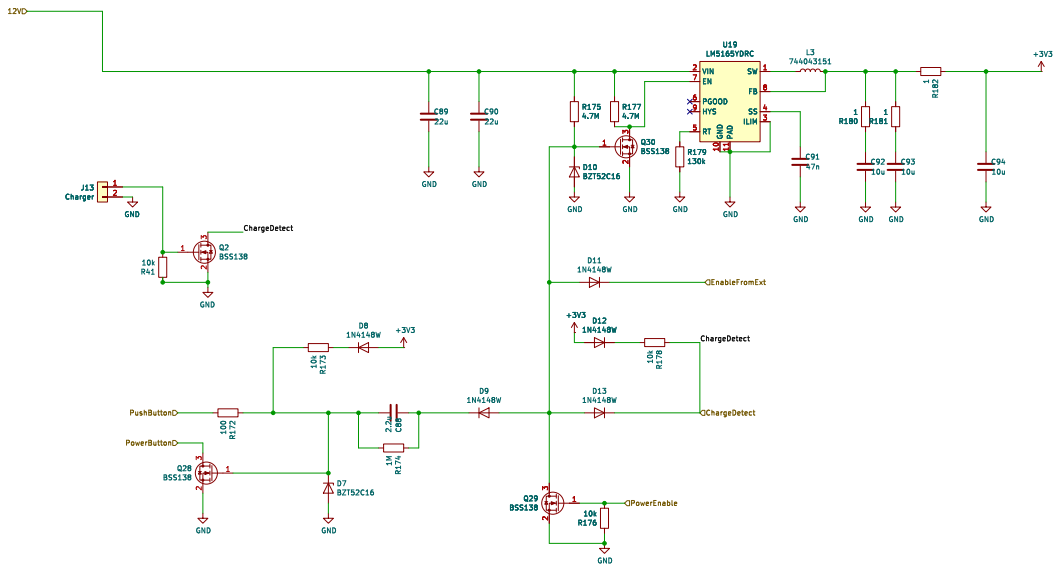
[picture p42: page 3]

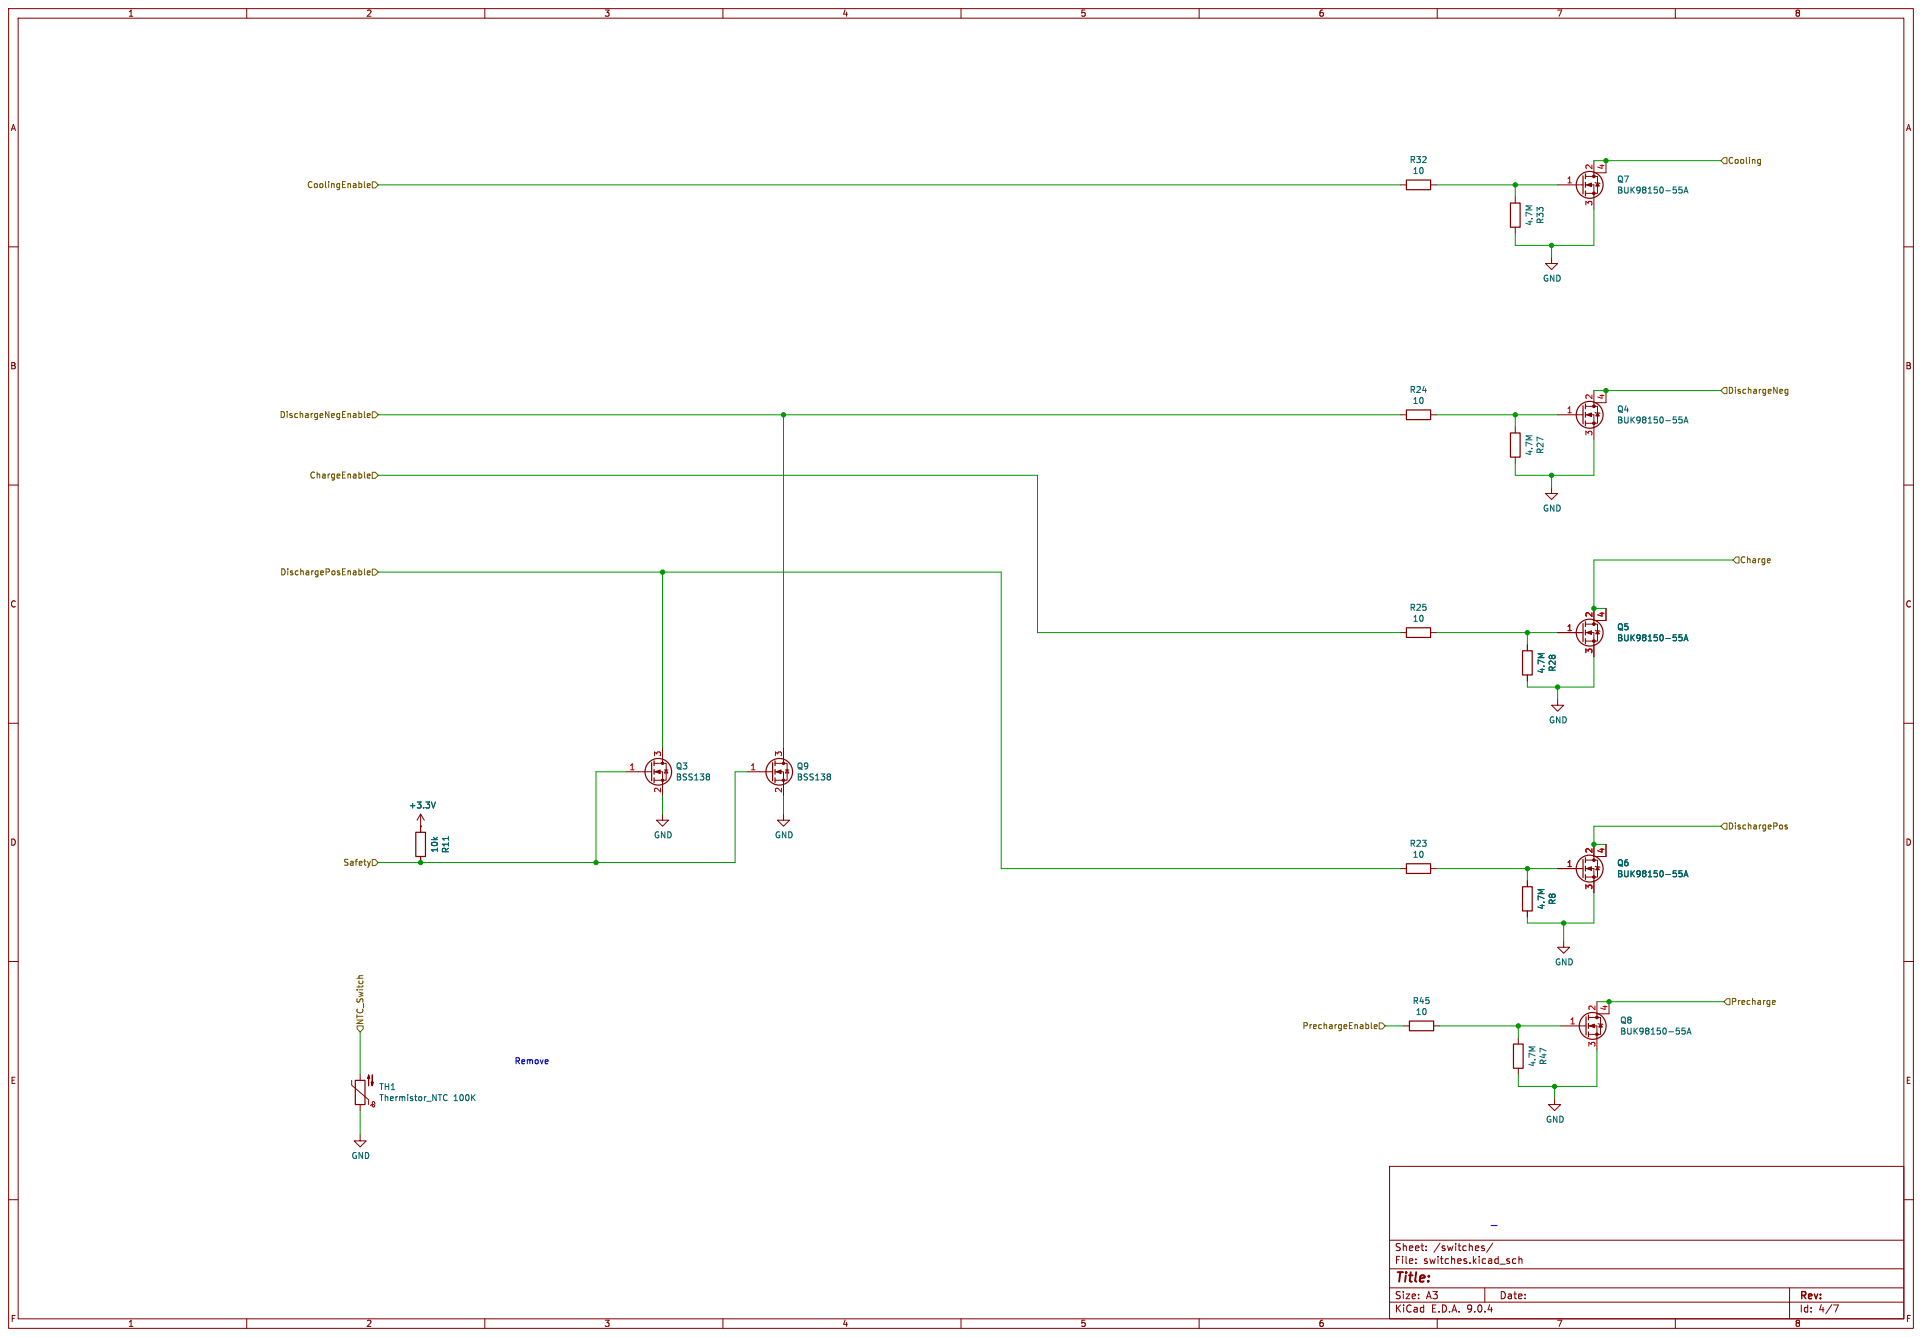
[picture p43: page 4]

Id: 4/7 Title: File: switches.kicad_sch Sheet: /switches/

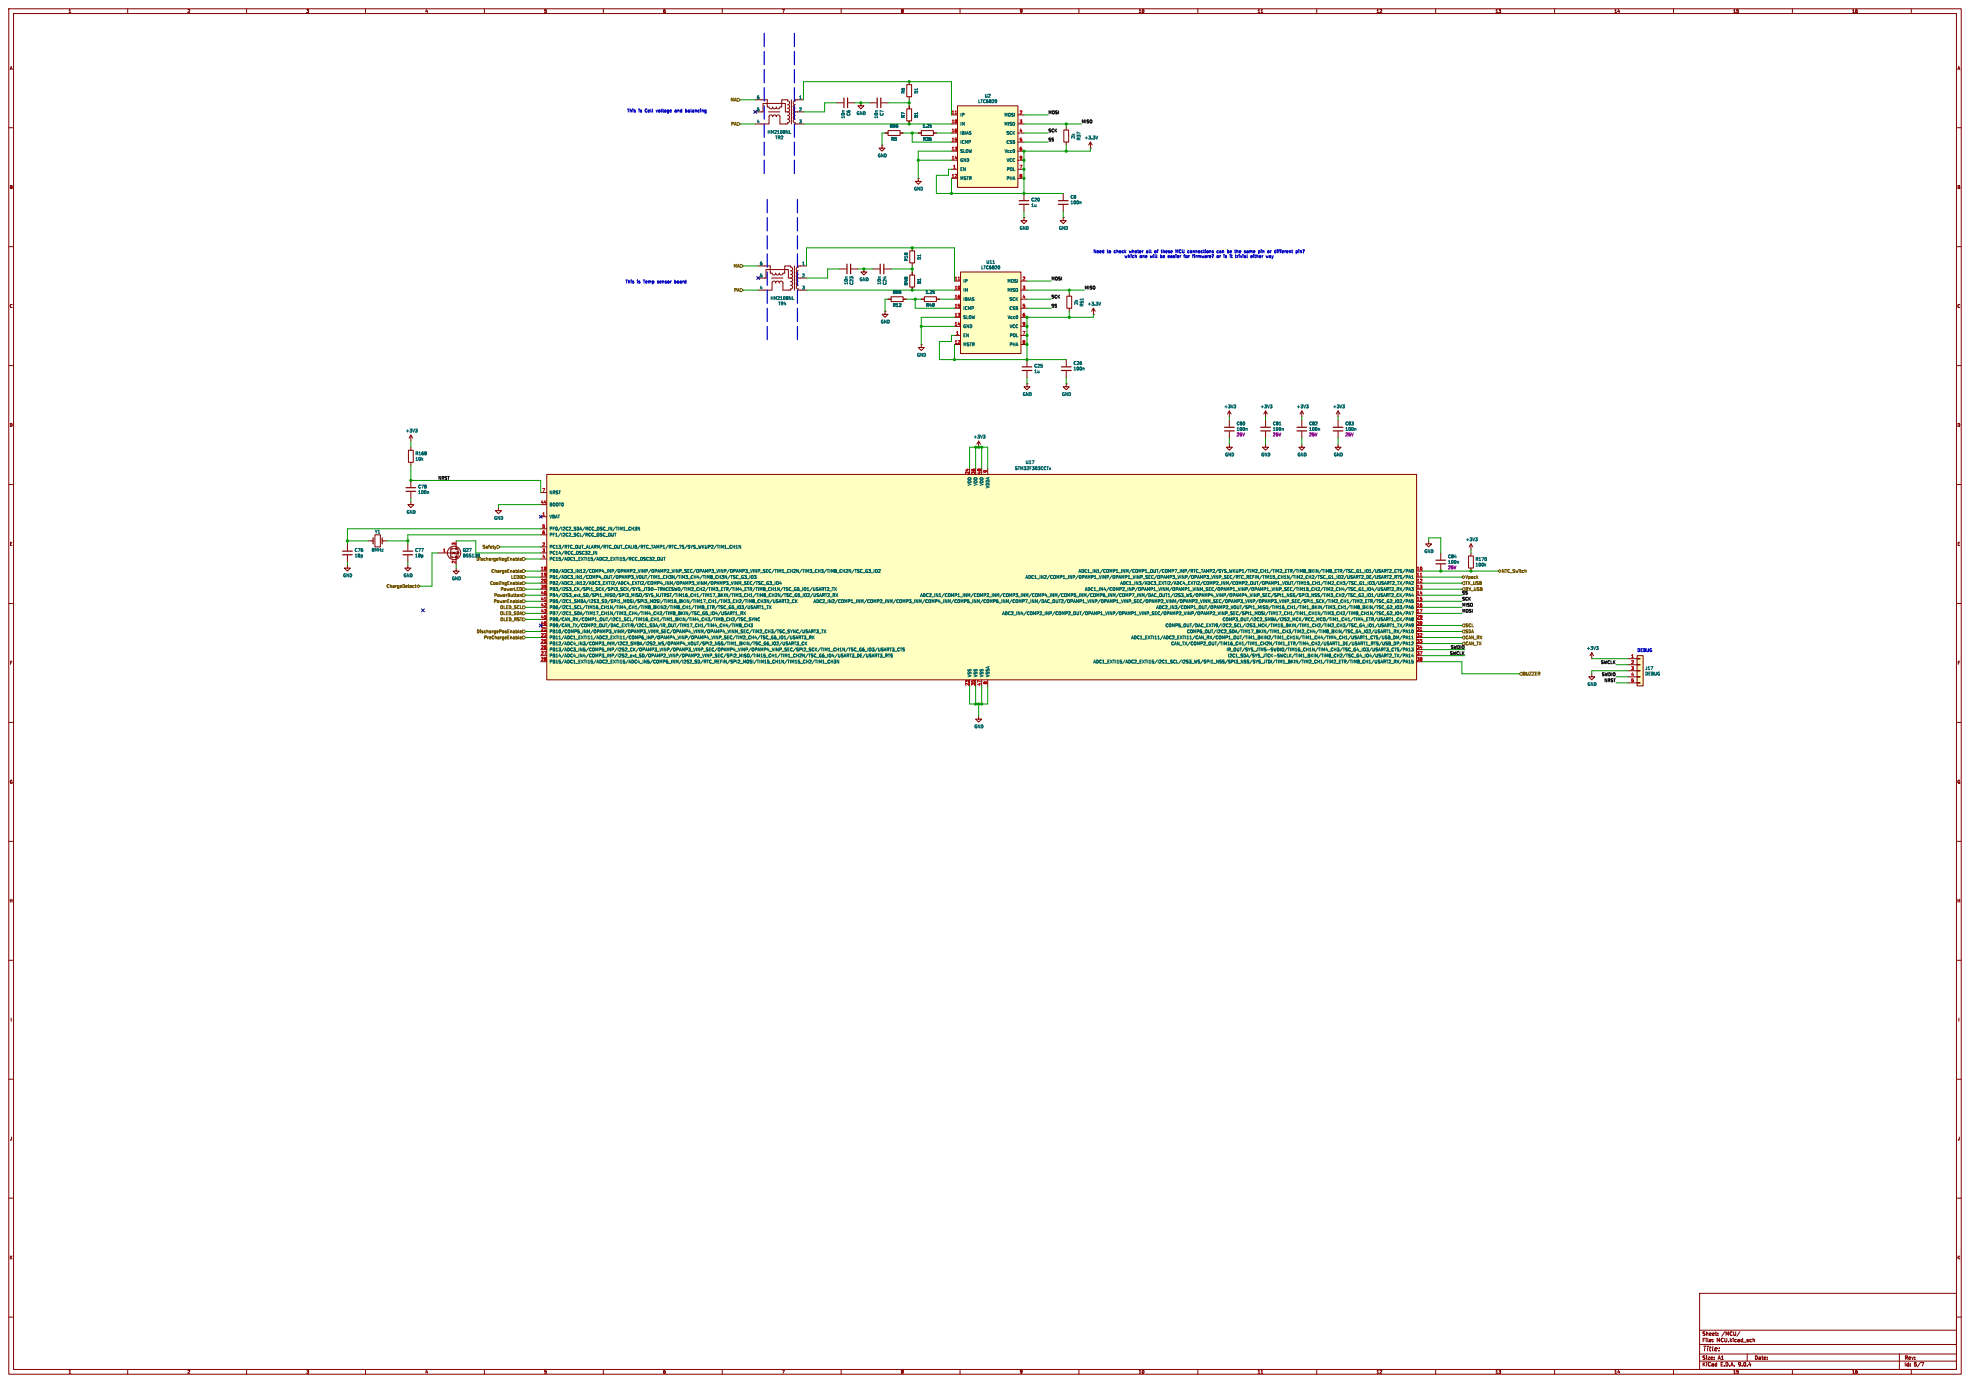
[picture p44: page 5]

Vpack PowerEnable PowerButton OLED_SDA OLED_SCL OLED_RST PreChargeEnable
PowerLED

Id: 5/7 Title: File: MCU.kicad_sch Sheet: /MCU/

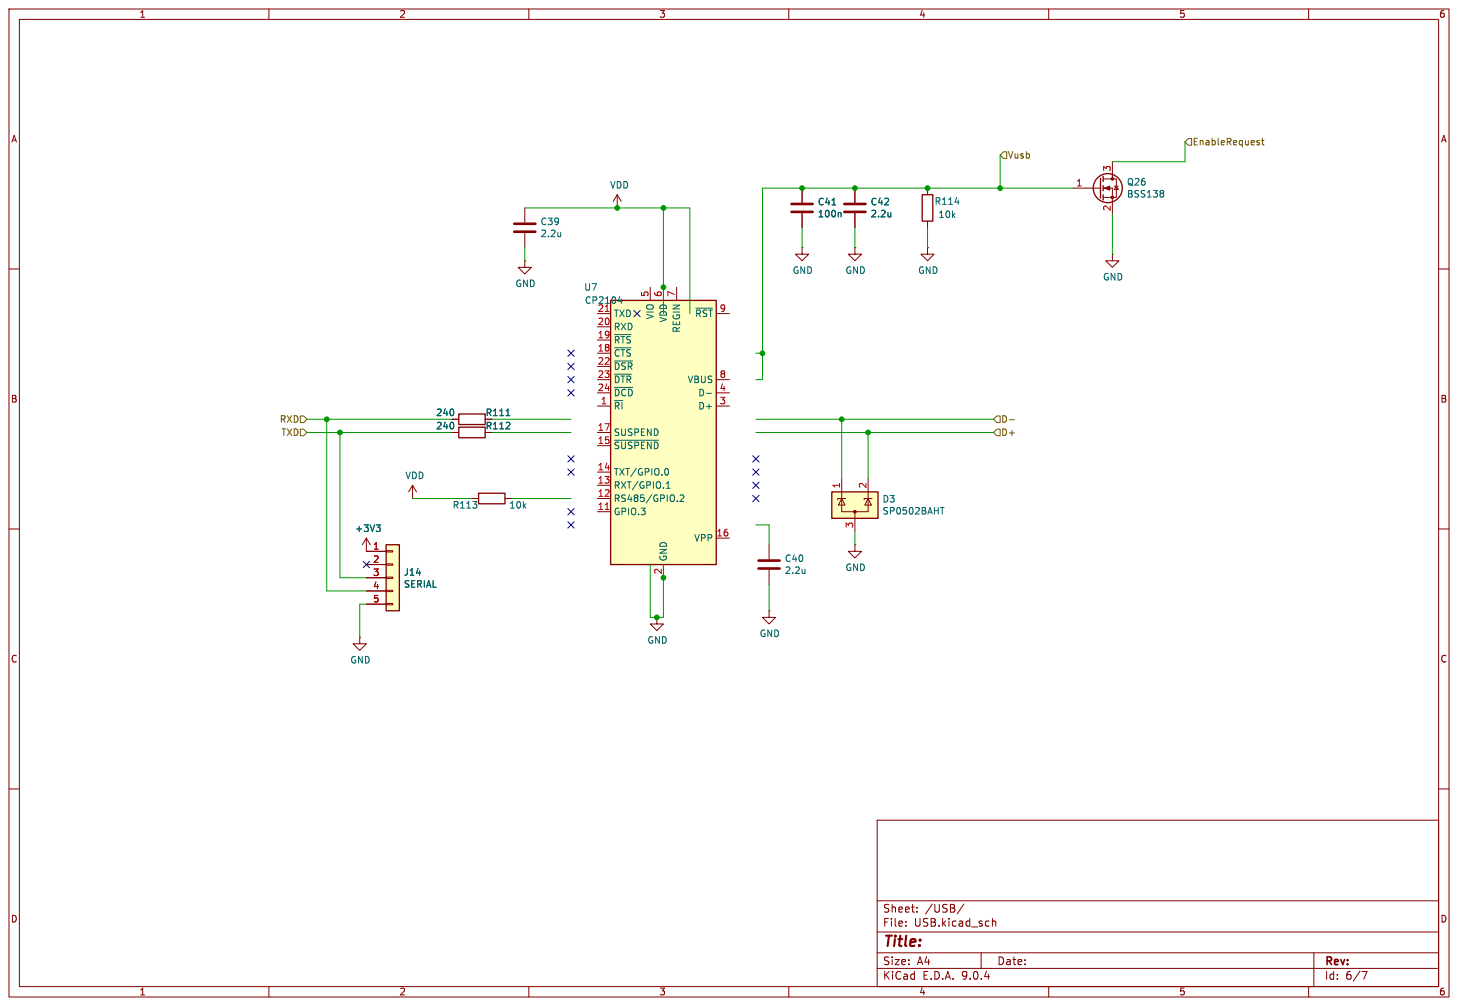
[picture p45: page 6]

5 TXD 21 RXD 20 ~{RTS} 19 ~{CTS} 18 ~{DSR} 22 ~{DTR} 23 ~{DCD} 24 ~{RI} 1 SUSPEND 17 ~{SUSPEND} 15 TXT/GPIO.0 14 RXT/GPIO.1 13 RS485/GPIO.2 12 GPIO.3 11 U7CP2104VDD

Id: 6/7 Title: File: USB.kicad_sch Sheet: /USB/

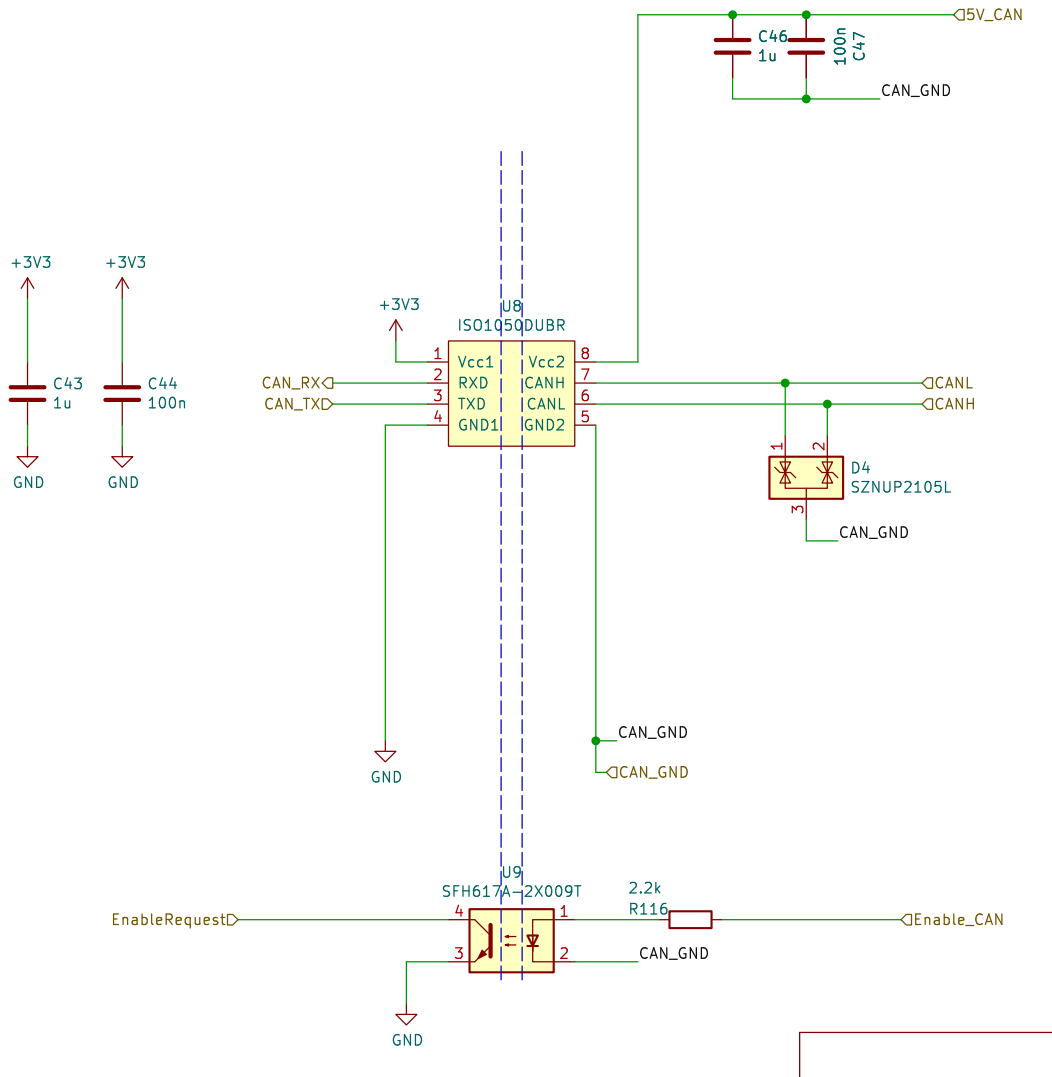
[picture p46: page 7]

Id: 7/7 Title: File: CAN.kicad_sch Sheet: /CAN/

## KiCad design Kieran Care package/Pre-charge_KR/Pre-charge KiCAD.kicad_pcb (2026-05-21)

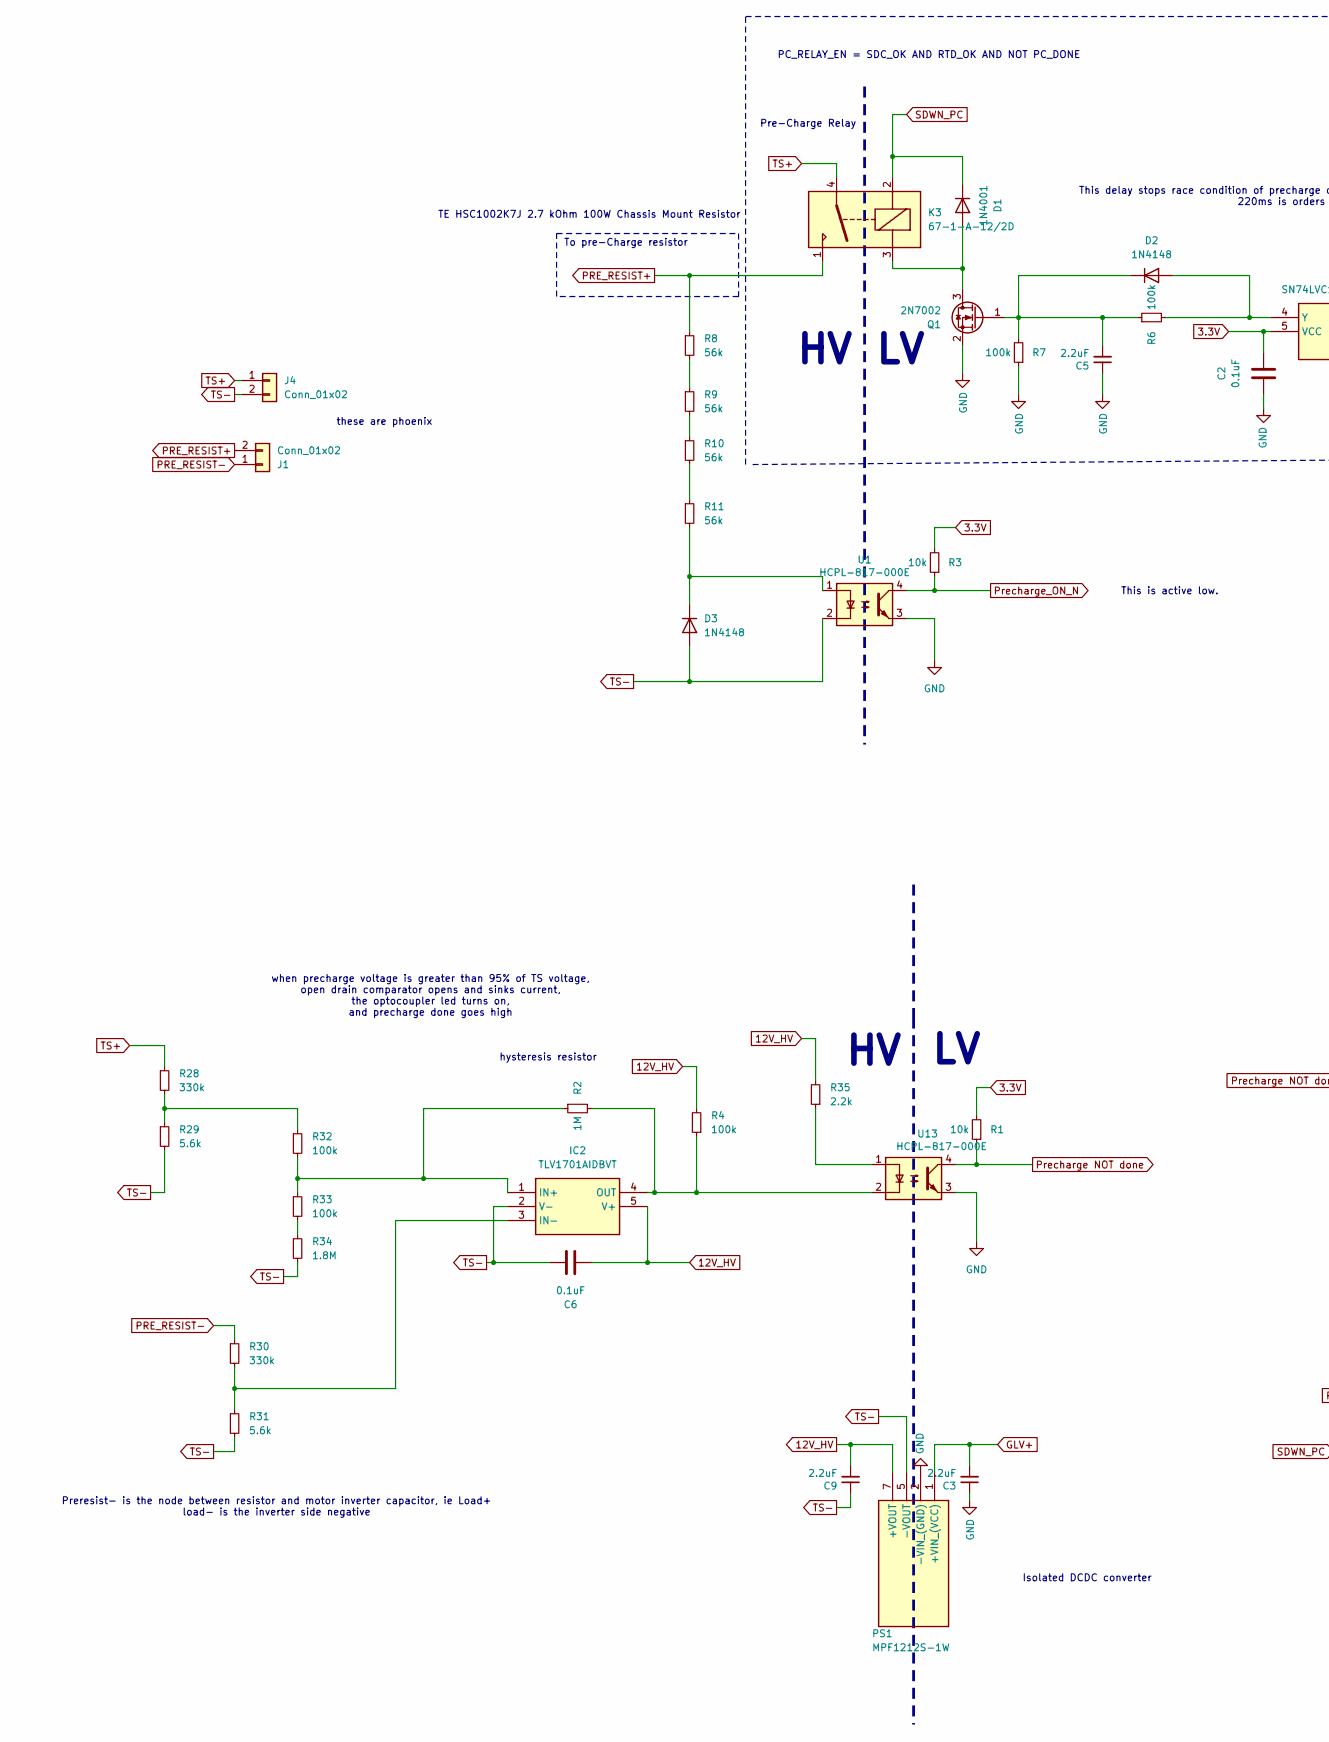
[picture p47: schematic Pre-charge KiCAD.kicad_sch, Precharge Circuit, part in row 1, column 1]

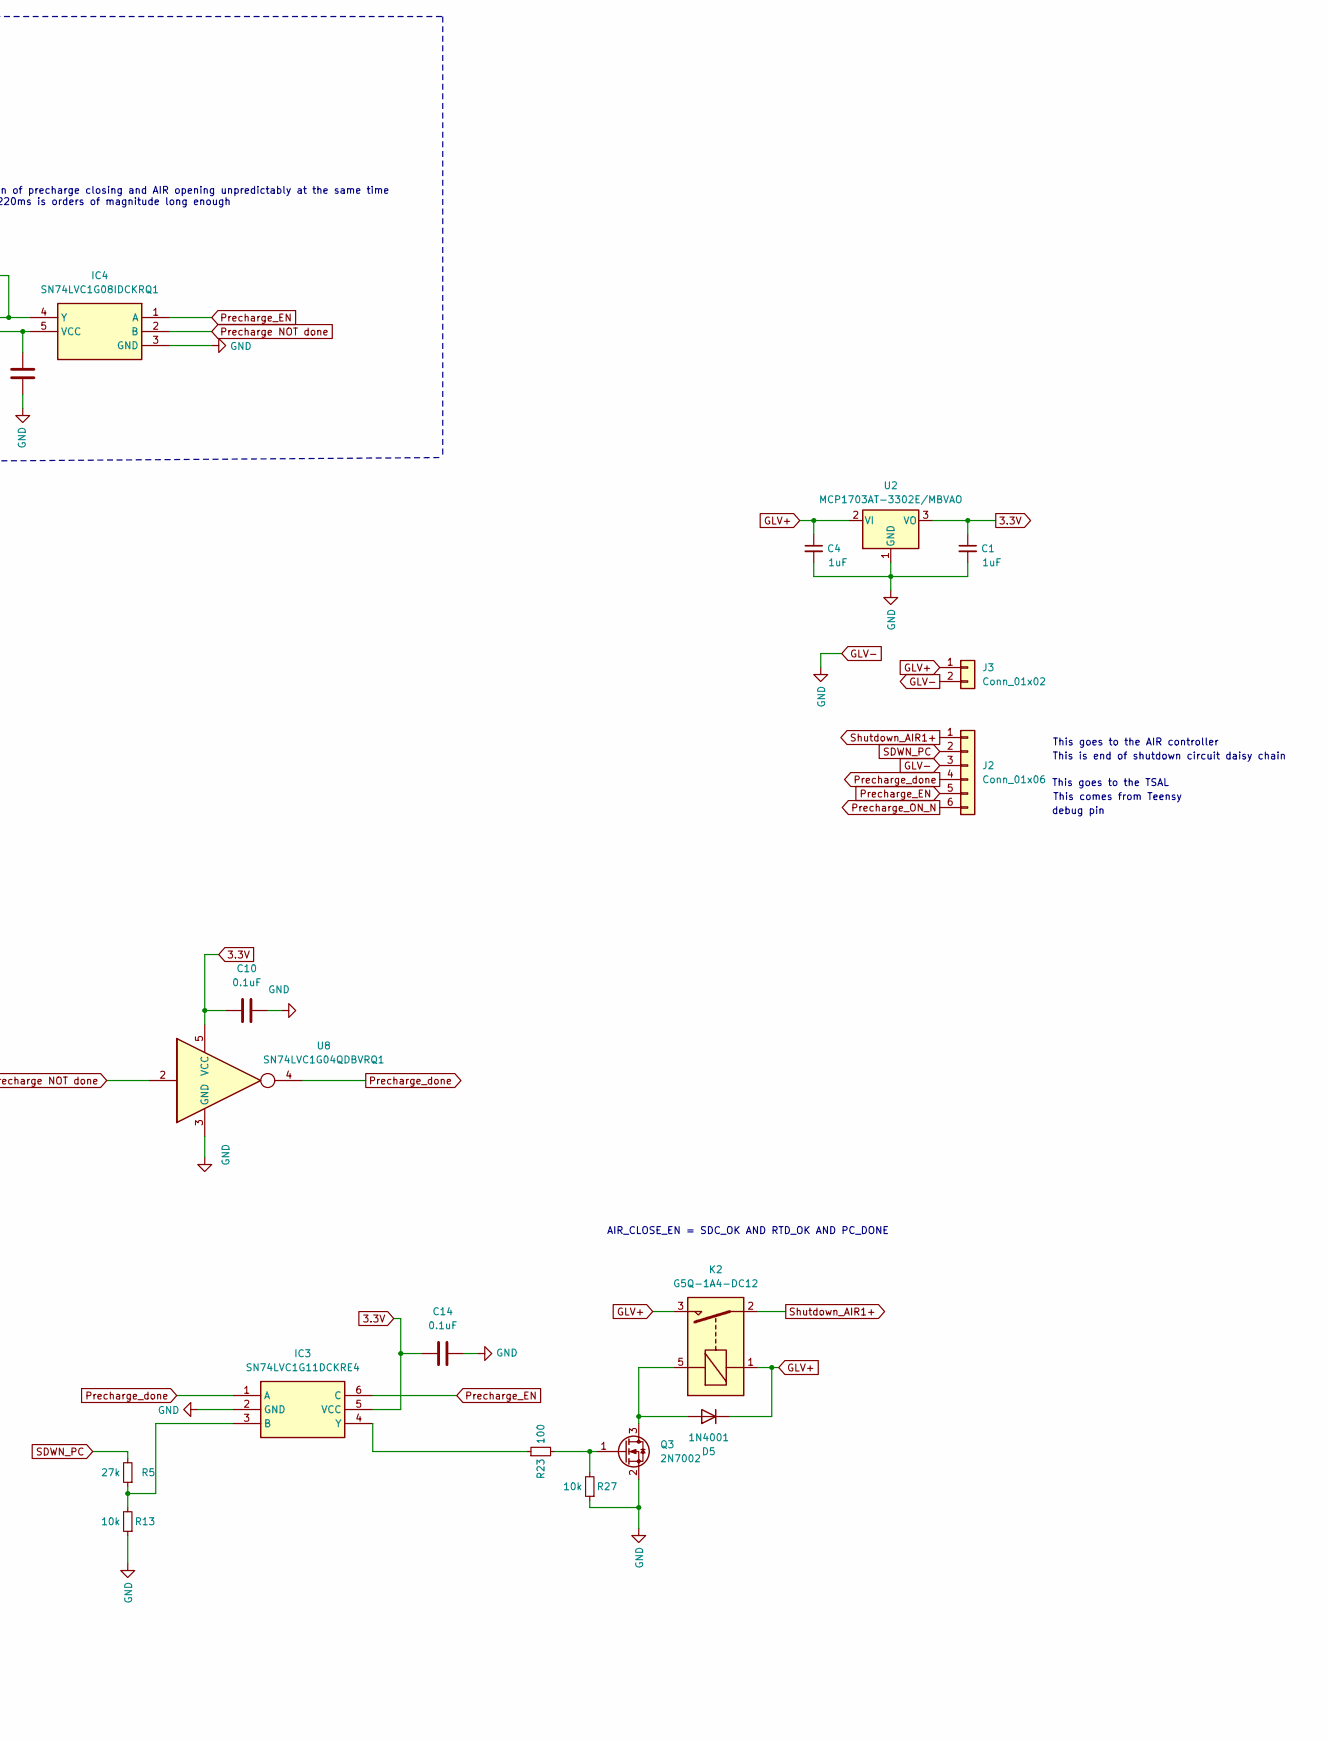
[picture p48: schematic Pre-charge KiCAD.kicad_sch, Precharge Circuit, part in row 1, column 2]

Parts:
C1, C4: 1uF; FA18X7R1H104KNU00; Part Number FA18X7R1E105KRU00
C2, C6, C10, C14: 0.1uF; FA18X7R1H104KNU00; Part Number FA18X7R1H104KNU00
C3, C5, C9: 2.2uF; FA14X7R1H224KNU00; Part Number FA14X7R1H225KRU00
D1, D5: 1N4001; D_DO-41_SOD81_P10.16mm_Horizontal; Part Number 1N4001
D2, D3: 1N4148; D_DO-35_SOD27_P7.62mm_Horizontal; Part Number 1N4148
IC2: TLV1701AIDBVT; SOT95P280X145-5N; Mouser Part Number 595-TLV1701AIDBVT
IC3: SN74LVC1G11DCKRE4; SOT65P210X110-6N; Mouser Part Number 595-74LVC1G11DCKRE4
IC4: SN74LVC1G08IDCKRQ1; SOT65P210X110-5N; Mouser Part Number 595-SN74LVC1G08IDCQ1
J1, J4: Conn_01x02; Phoenix_1x2_1729128; Part Number 1729128
J2: Conn_01x06; JST_XH_B6B-XH-A_1x06_P2.50mm_Vertical; Part Number B6B-XH-A
J3: Conn_01x02; JST_XH_B2B-XH-A_1x02_P2.50mm_Vertical; Part Number B2B-XH-A
K2: G5Q-1A4-DC12; Relay_SPST_Omron-G5Q-1A; Part Number G5Q-1A4-DC12
K3: 67-1-A-12/2D; 67-1-A-12_2D; Part Number 67-1-A-12/2D
PS1: MPF1212S-1W; Part Number MPF1212S-1W
Q1, Q3: 2N7002; SOT-23; Part Number 2N7002
R1, R3, R13, R27: 10k; R_Axial_DIN0207_L6.3mm_D2.5mm_P10.16mm_Horizontal; Part Number MCF 0.25W 10K
R2: 1M; R_Axial_DIN0207_L6.3mm_D2.5mm_P10.16mm_Horizontal; Part Number MCF 0.25W 1M
R4, R6, R7, R32, R33: 100k; R_Axial_DIN0207_L6.3mm_D2.5mm_P10.16mm_Horizontal; Part Number MCF 0.25W 100K
R5: 27k; R_Axial_DIN0207_L6.3mm_D2.5mm_P10.16mm_Horizontal; Part Number MCF 0.25W 27K
R8, R9, R10, R11: 56k; R_Axial_DIN0411_L9.9mm_D3.6mm_P12.70mm_Horizontal; Part Number MCF 0.5W 56K
R23: 100; R_Axial_DIN0207_L6.3mm_D2.5mm_P10.16mm_Horizontal; Part Number MCF 0.25W 100R
R28, R30: 330k; R_Axial_DIN0411_L9.9mm_D3.6mm_P12.70mm_Horizontal; Part Number MCF 0.5W 330K
R29, R31: 5.6k; R_Axial_DIN0207_L6.3mm_D2.5mm_P10.16mm_Horizontal; Part Number MCF 0.25W 5K6
R34: 1.8M; R_Axial_DIN0207_L6.3mm_D2.5mm_P10.16mm_Horizontal; Part Number MCF 0.25W 1.8M
R35: 2.2k; R_Axial_DIN0207_L6.3mm_D2.5mm_P10.16mm_Horizontal; Part Number MCF 0.25W 2.2k
U1, U13: HCPL-817-000E; DIP-4_W7.62mm; Part Number HCPL-817-000E
U2: MCP1703AT-3302E/MBVAO; SOT-89-3; Part Number MCP1703AT-3302E/MBVAO
U8: SN74LVC1G04QDBVRQ1; SOT-23-5; Part Number SN74LVC1G04QDBVRQ1

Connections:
3.3V: C1.1, C2.1, C10.1, C14.1, IC3.5 (VCC), IC4.5 (VCC), R1.2, R3.2, U2.3 (VO), U8.5 (VCC)
12V_HV: C6.1, C9.2, IC2.5 (V+), PS1.7 (+VOUT), R4.2, R35.2
GLV+: C3.2, C4.1, D5.1 (K), J3.1, K2.1, K2.3, PS1.1 (+VIN_(VCC)), U2.2 (VI)
GLV-: C1.2, C2.2, C3.1, C4.2, C5.1, C10.2, C14.2, IC3.2 (GND), IC4.3 (GND), J2.3, J3.2, PS1.2 (-VIN_(GND)), Q1.2 (S), Q3.2 (S), R7.1, R13.1, R27.1, U1.3, U2.1 (GND), U8.3 (GND), U13.3
unnamed: D1.2 (A), K3.3, Q1.3 (D)
unnamed: D2.2 (A), IC4.4 (Y), R6.2
unnamed: C5.2, D2.1 (K), Q1.1 (G), R6.1, R7.2
unnamed: D3.1 (K), R11.2, U1.1
unnamed: D5.2 (A), K2.5, Q3.3 (D)
unnamed: IC2.1 (IN+), R2.1, R32.2, R33.1
unnamed: IC2.3 (IN-), R30.2, R31.1
unnamed: IC2.4 (OUT), R2.2, R4.1, U13.2
unnamed: IC3.3 (B), R5.1, R13.2
unnamed: IC3.4 (Y), R23.1
unnamed: Q3.1 (G), R23.2, R27.2
unnamed: R8.2, R9.1
unnamed: R9.2, R10.1
unnamed: R10.2, R11.1
unnamed: R28.2, R29.1, R32.1
unnamed: R33.2, R34.1
unnamed: R35.1, U13.1
PRE_RESIST+: J1.2, K3.1, R8.1
PRE_RESIST-: J1.1, R30.1
Precharge NOT done: IC4.2 (B), R1.1, U8.2, U13.4
Precharge_EN: IC3.6 (C), IC4.1 (A), J2.5
Precharge_ON_N: J2.6, R3.1, U1.4
Precharge_done: IC3.1 (A), J2.4, U8.4
SDWN_PC: D1.1 (K), J2.2, K3.2, R5.2
Shutdown_AIR1+: J2.1, K2.2
TS+: J4.1, K3.4, R28.1
TS-: C6.2, C9.1, D3.2 (A), IC2.2 (V-), J4.2, PS1.5 (-VOUT), R29.2, R31.2, R34.2, U1.2

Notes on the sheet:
This is end of shutdown circuit daisy chain
This goes to the TSAL
PC_RELAY_EN = SDC_OK AND RTD_OK AND NOT PC_DONE
This comes from Teensy
AIR_CLOSE_EN = SDC_OK AND RTD_OK AND PC_DONE
hysteresis resistor
This goes to the AIR controller
To pre-Charge resistor
TE HSC1002K7J 2.7 kOhm 100W Chassis Mount Resistor
Isolated DCDC converter
debug pin
when precharge voltage is greater than 95% of TS voltage, open drain comparator opens and sinks current, the optocoupler led turns on, and precharge done goes high
Preresist- is the node between resistor and motor inverter capacitor, ie Load+ load- is the inverter side negative
these are phoenix
This is active low.
This delay stops race condition of precharge closing and AIR opening unpredictably at the same time 220ms is orders of magnitude long enough
Pre-Charge Relay

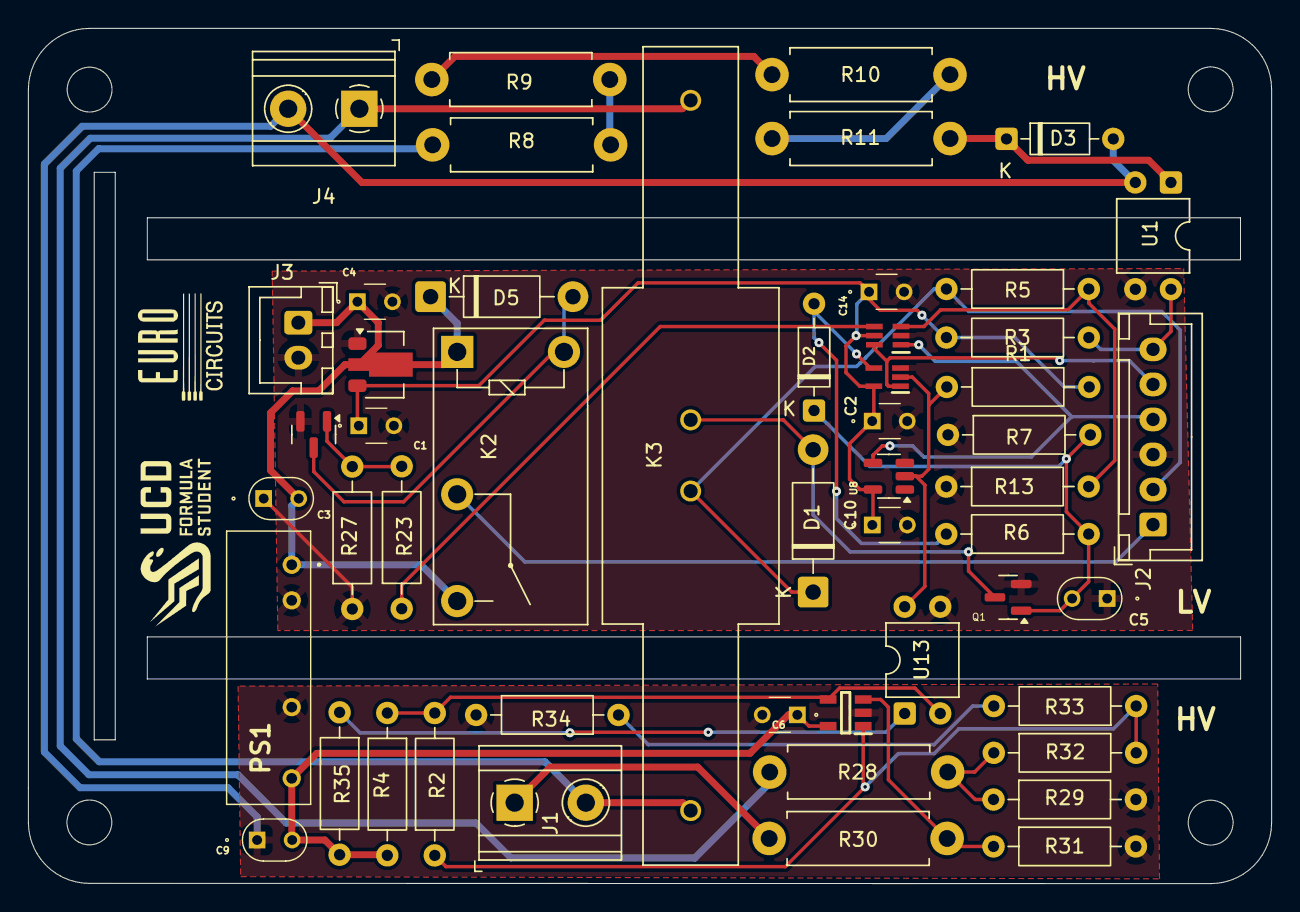
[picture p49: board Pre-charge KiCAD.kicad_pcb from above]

Board: 2 copper layers, 88.7 x 61.0 mm, 51 parts (0 on the bottom side), 31 nets.

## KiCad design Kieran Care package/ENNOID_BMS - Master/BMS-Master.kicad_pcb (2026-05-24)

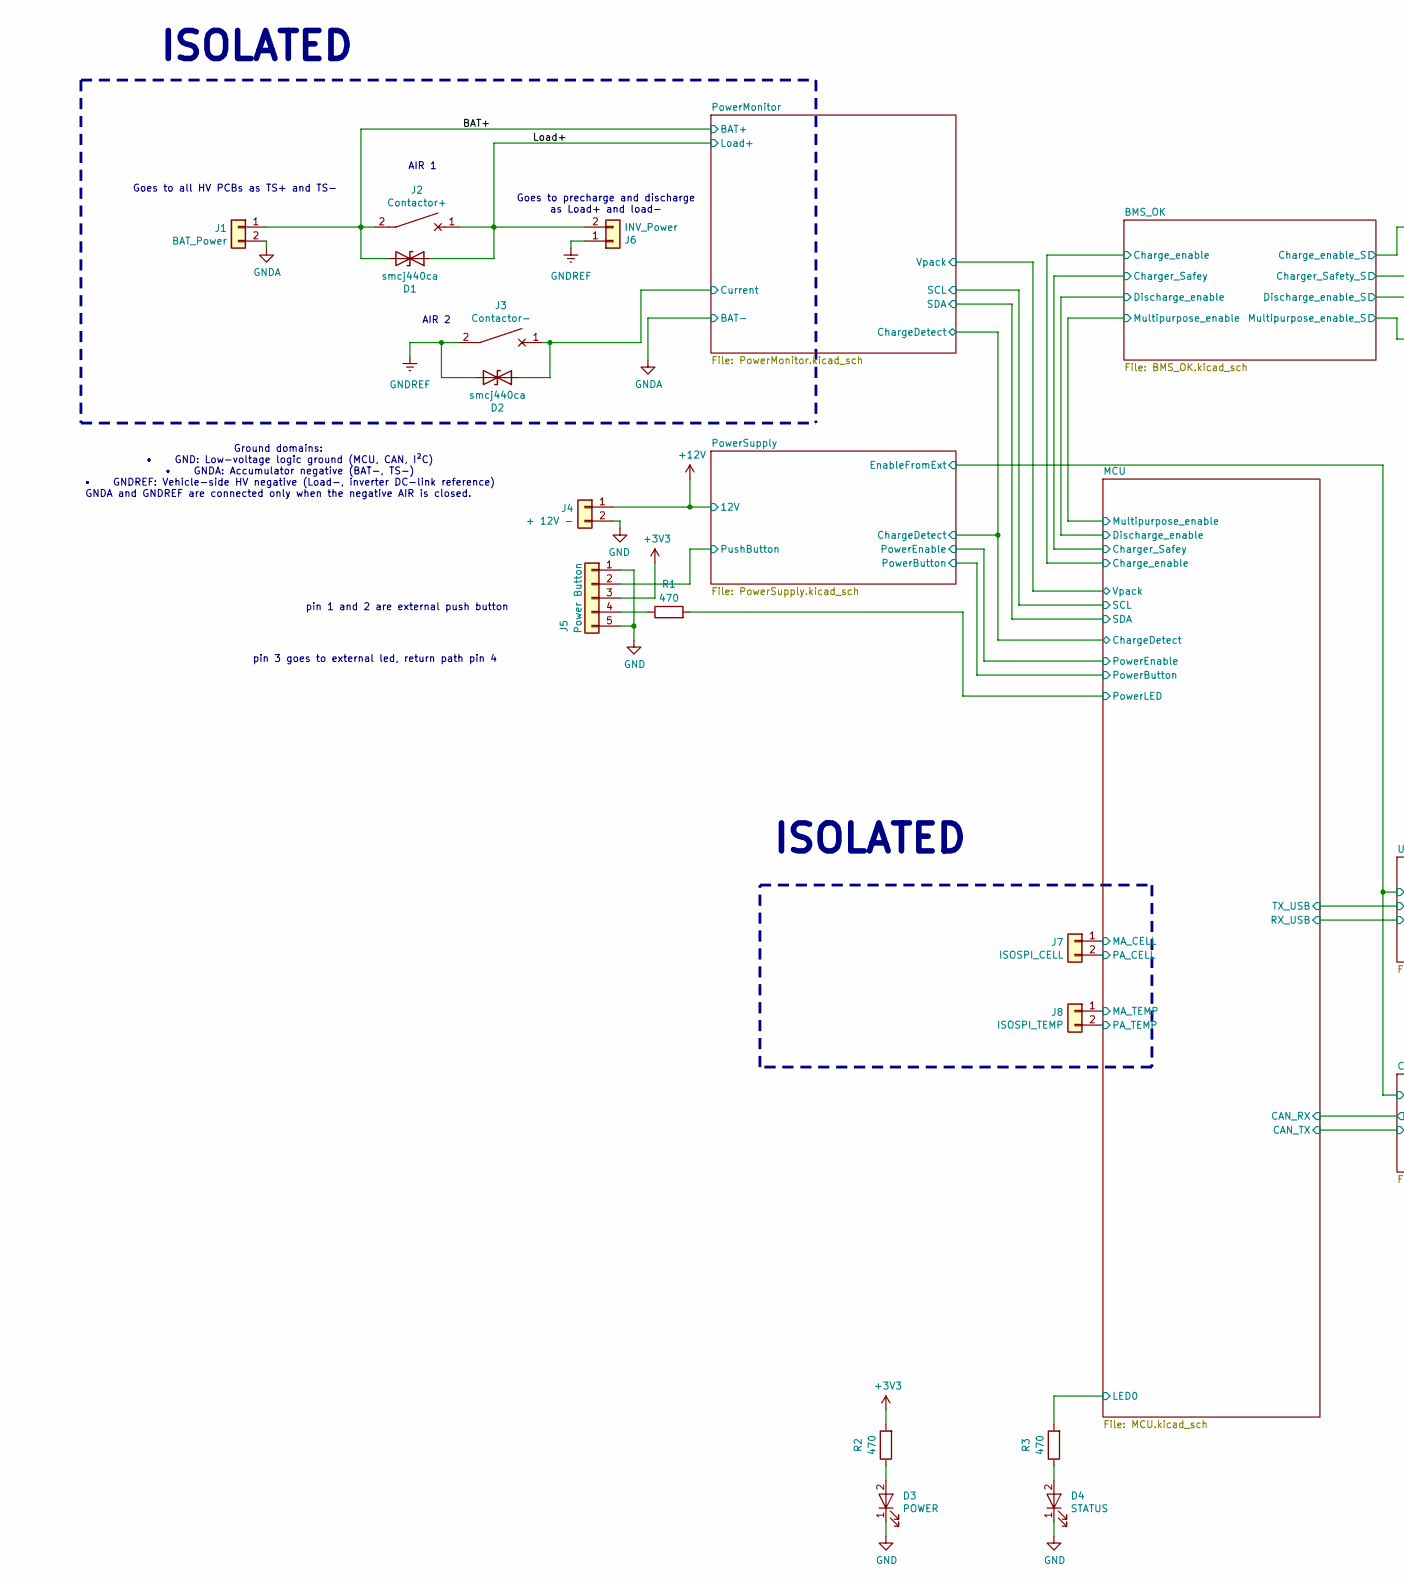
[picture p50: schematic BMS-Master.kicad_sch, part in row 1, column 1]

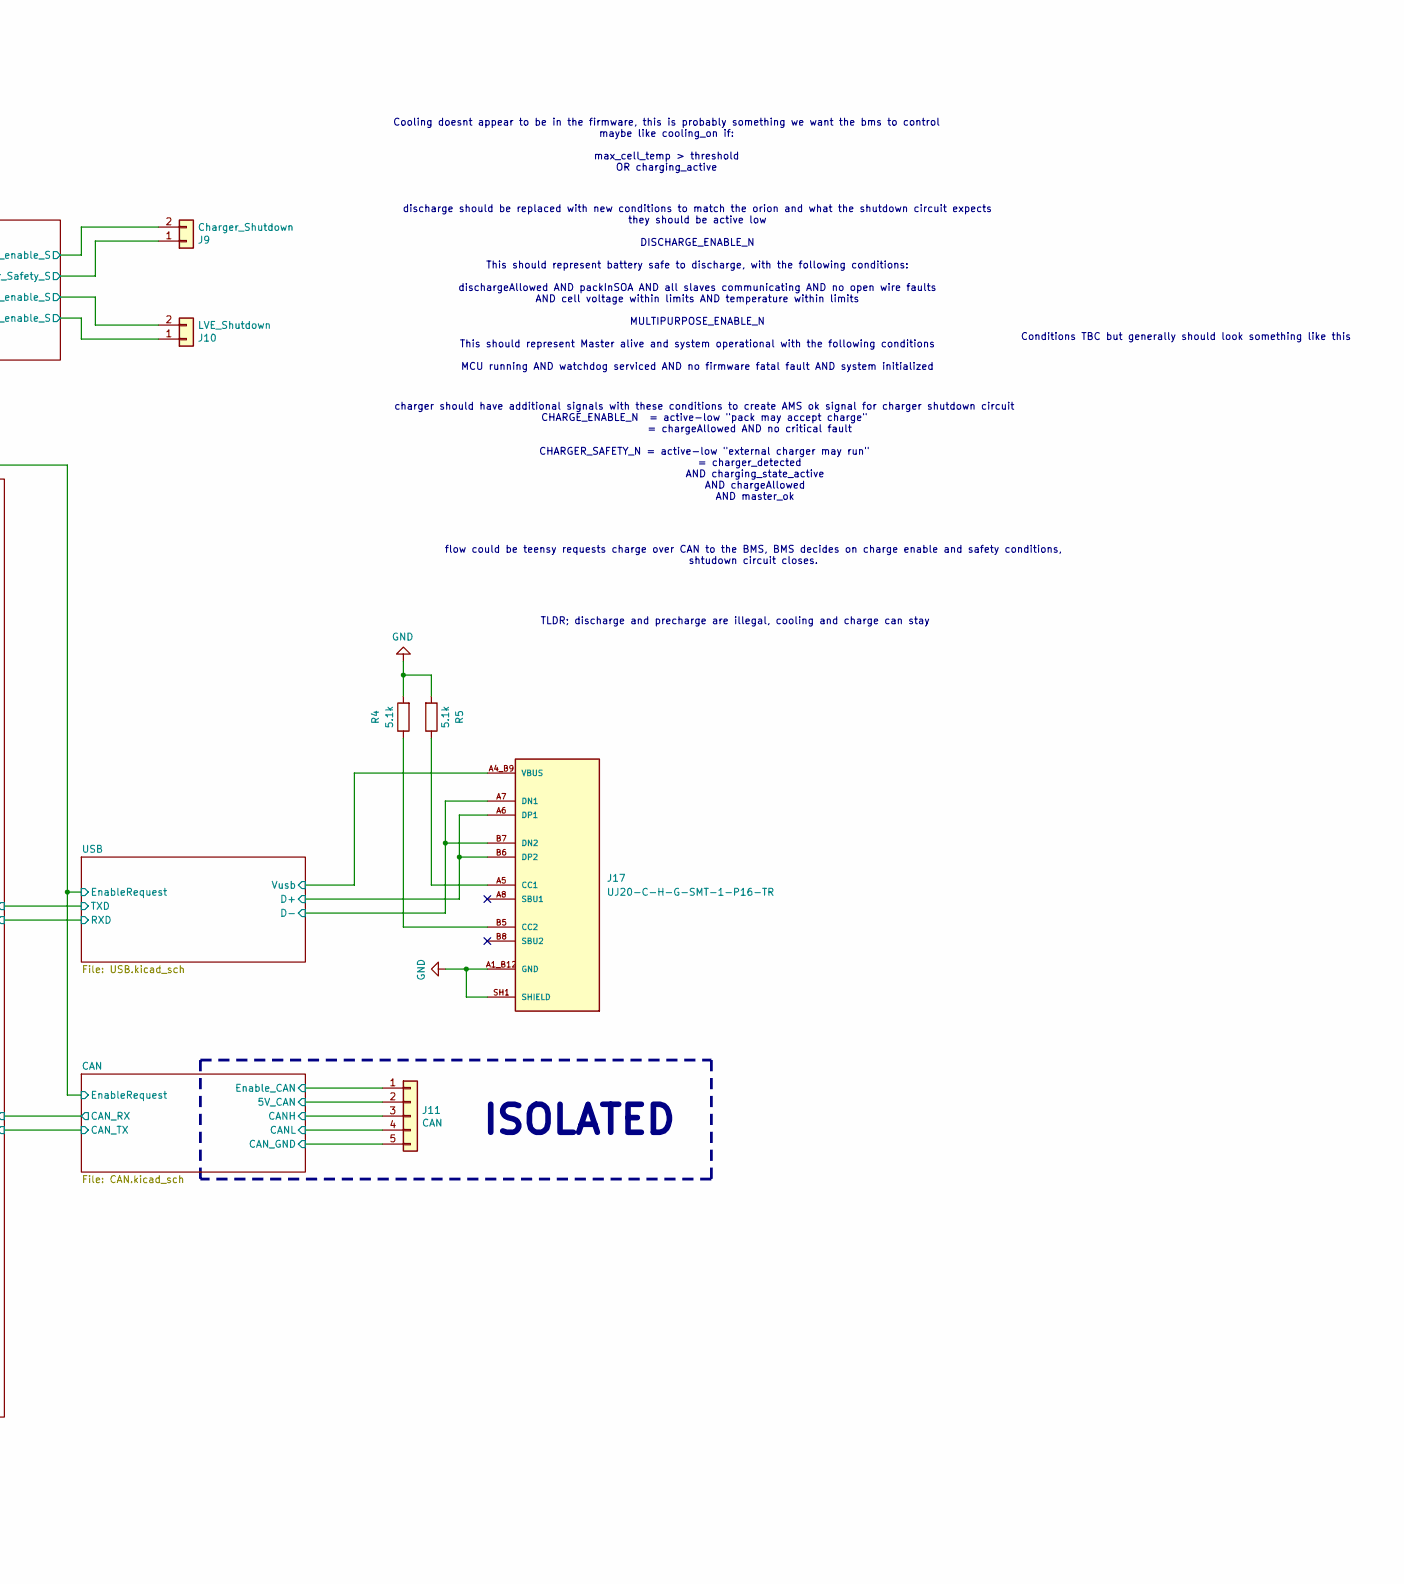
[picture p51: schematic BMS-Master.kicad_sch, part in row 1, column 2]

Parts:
D1, D2: smcj440ca; D_SMC; MPN smcj440ca
D3: POWER; LED_0603_1608Metric; MPN SML-D12P8WT86C
D4: STATUS; LED_0603_1608Metric; MPN SML-D12P8WT86C
J1: BAT_Power; Phoenix_1x2_1729128; MPN 1729128
J2: Contactor+; EVC500; MPN N/A
J3: Contactor-; EVC500; MPN N/A
J4: + 12V -; JST_XH_B2B-XH-A_1x02_P2.50mm_Vertical; MPN B2B-XH-A
J5: Power Button; JST_XH_B5B-XH-A_1x05_P2.50mm_Vertical; MPN B5B-XH-A
J6: INV_Power; Phoenix_1x2_1729128; MPN 1729128
J7: ISOSPI_CELL; JST_XH_B2B-XH-A_1x02_P2.50mm_Vertical; MPN B2B-XH-A
J8: ISOSPI_TEMP; JST_XH_B2B-XH-A_1x02_P2.50mm_Vertical; MPN B2B-XH-A
J9: Charger_Shutdown; JST_XH_B2B-XH-A_1x02_P2.50mm_Vertical; MPN B2B-XH-A
J10: LVE_Shutdown; JST_XH_B2B-XH-A_1x02_P2.50mm_Vertical; MPN B2B-XH-A
J11: CAN; JST_XH_B5B-XH-A_1x05_P2.50mm_Vertical; MPN B5B-XH-A
J17: UJ20-C-H-G-SMT-1-P16-TR; SAMESKY_UJ20-C-H-G-SMT-1-P16-TR; MPN UJ20-C-H-G-SMT-1-P16-TR
R1, R2, R3: 470; R_0603_1608Metric; MPN RC0603JR-07470RL
R4, R5: 5.1k; R_0603_1608Metric; MPN RC0603JR-075K1L

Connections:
+3V3: J5.3, R2.2; also elsewhere on the board
+12V: J4.1; also elsewhere on the board
/BAT+: D1.2 (A2), J1.1, J2.2; also elsewhere on the board
/BMS_OK/Charge_enable_S: J9.2; also elsewhere on the board
/BMS_OK/Charger_Safety_S: J9.1; also elsewhere on the board
/BMS_OK/Discharge_enable_S: J10.2; also elsewhere on the board
/BMS_OK/Multipurpose_enable_S: J10.1; also elsewhere on the board
/CAN/5V_CAN: J11.2; also elsewhere on the board
/CAN/CANH: J11.3; also elsewhere on the board
/CAN/CANL: J11.4; also elsewhere on the board
/CAN/CAN_GND: J11.5; also elsewhere on the board
/CAN/Enable_CAN: J11.1; also elsewhere on the board
/Load+: D1.1 (A1), J2.1, J6.2; also elsewhere on the board
/MCU/LED0: R3.2; also elsewhere on the board
/MCU/MA_CELL: J7.1; also elsewhere on the board
/MCU/MA_TEMP: J8.1; also elsewhere on the board
/MCU/PA_CELL: J7.2; also elsewhere on the board
/MCU/PA_TEMP: J8.2; also elsewhere on the board
/MCU/PowerLED: R1.2; also elsewhere on the board
/PowerMonitor/Current: D2.1 (A1), J3.1; also elsewhere on the board
/PowerSupply/PushButton: J5.2; also elsewhere on the board
/USB/D+: J17.A6 (DP1), J17.B6 (DP2); also elsewhere on the board
/USB/D-: J17.A7 (DN1), J17.B7 (DN2); also elsewhere on the board
/USB/Vusb: J17.A4_B9 (VBUS), J17.B4_A9 (VBUS); also elsewhere on the board
GND: D3.1 (K), D4.1 (K), J4.2, J5.1, J5.5, J17.A1_B12 (GND), J17.B1_A12 (GND), J17.SH1 (SHIELD), J17.SH2 (SHIELD), J17.SH3 (SHIELD), J17.SH4 (SHIELD), R4.2, R5.2; also elsewhere on the board
GNDA: J1.2; also elsewhere on the board
GNDREF: D2.2 (A2), J3.2, J6.1; also elsewhere on the board
unnamed: D3.2 (A), R2.1
unnamed: D4.2 (A), R3.1
unnamed: J5.4, R1.1
unnamed: J17.A5 (CC1), R5.1
unnamed: J17.B5 (CC2), R4.1

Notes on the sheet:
Ground domains: • GND: Low-voltage logic ground (MCU, CAN, I²C) • GNDA: Accumulator negative (BAT−, TS−) • GNDREF: Vehicle-side HV negative (Load−, inverter DC-link reference) GNDA and GNDREF are connected only when the negative AIR is closed.
Goes to all HV PCBs as TS+ and TS-
flow could be teensy requests charge over CAN to the BMS, BMS decides on charge enable and safety conditions, shtudown circuit closes.
Conditions TBC but generally should look something like this
AIR 1
ISOLATED
pin 3 goes to external led, return path pin 4
charger should have additional signals with these conditions to create AMS ok signal for charger shutdown circuit CHARGE_ENABLE_N = active-low "pack may accept charge" = chargeAllowed AND no critical fault CHARGER_SAFETY_N = active-low "external charger may run" = charger_detected AND charging_stat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
AIR 2
Cooling doesnt appear to be in the firmware, this is probably something we want the bms to control maybe like cooling_on if: max_cell_temp > threshold OR charging_active
discharge should be replaced with new conditions to match the orion and what the shutdown circuit expects they should be active low DISCHARGE_ENABLE_N This should represent battery safe to discharge, with the following conditions: dischargeAllowed AND packInSOA AND all slaves communicating AND no o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
Goes to precharge and discharge as Load+ and load-
pin 1 and 2 are external push button
TLDR; discharge and precharge are illegal, cooling and charge can stay

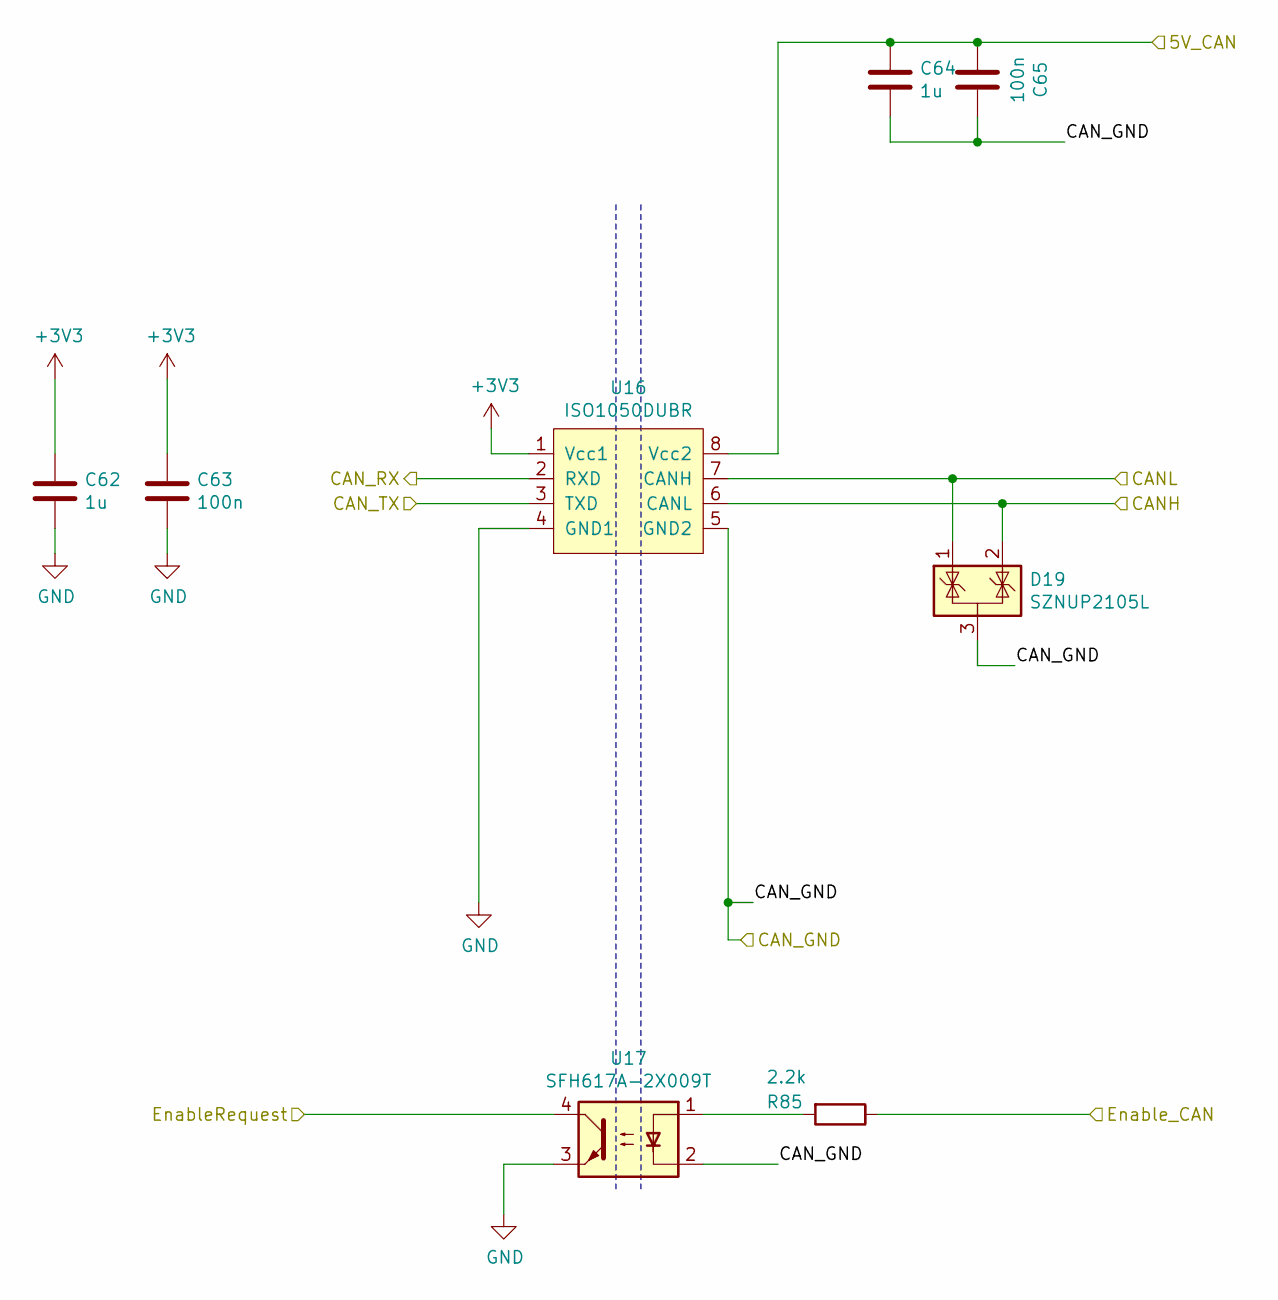
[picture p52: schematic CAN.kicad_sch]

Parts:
C62, C64: 1u; C_0603_1608Metric; MPN GRM188R71E105KA12D
C63, C65: 100n; C_0603_1608Metric; MPN GRM188R71E104KA01D
D19: SZNUP2105L; SOT-23; MPN SZNUP2105LT1G
R85: 2.2k; R_0603_1608Metric; MPN RC0603JR-072K2L
U16: ISO1050DUBR; ISO1050; MPN ISO1050DUBR
U17: SFH617A-2X009T; SMDIP-4_W9.53mm_Clearance8mm; MPN SFH617A-2X009T

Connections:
+3V3: C62.1, C63.1, U16.1 (Vcc1); also elsewhere on the board
/CAN/5V_CAN: C64.1, C65.2, U16.8 (Vcc2); also elsewhere on the board
/CAN/CANH: D19.2 (K), U16.6 (CANL); also elsewhere on the board
/CAN/CANL: D19.1 (K), U16.7 (CANH); also elsewhere on the board
/CAN/CAN_GND: C64.2, C65.1, D19.3 (A), U16.5 (GND2), U17.2; also elsewhere on the board
/CAN/CAN_RX: U16.2 (RXD); also elsewhere on the board
/CAN/CAN_TX: U16.3 (TXD); also elsewhere on the board
/CAN/EnableRequest: U17.4; also elsewhere on the board
/CAN/Enable_CAN: R85.1; also elsewhere on the board
GND: C62.2, C63.2, U16.4 (GND1), U17.3; also elsewhere on the board
unnamed: R85.2, U17.1

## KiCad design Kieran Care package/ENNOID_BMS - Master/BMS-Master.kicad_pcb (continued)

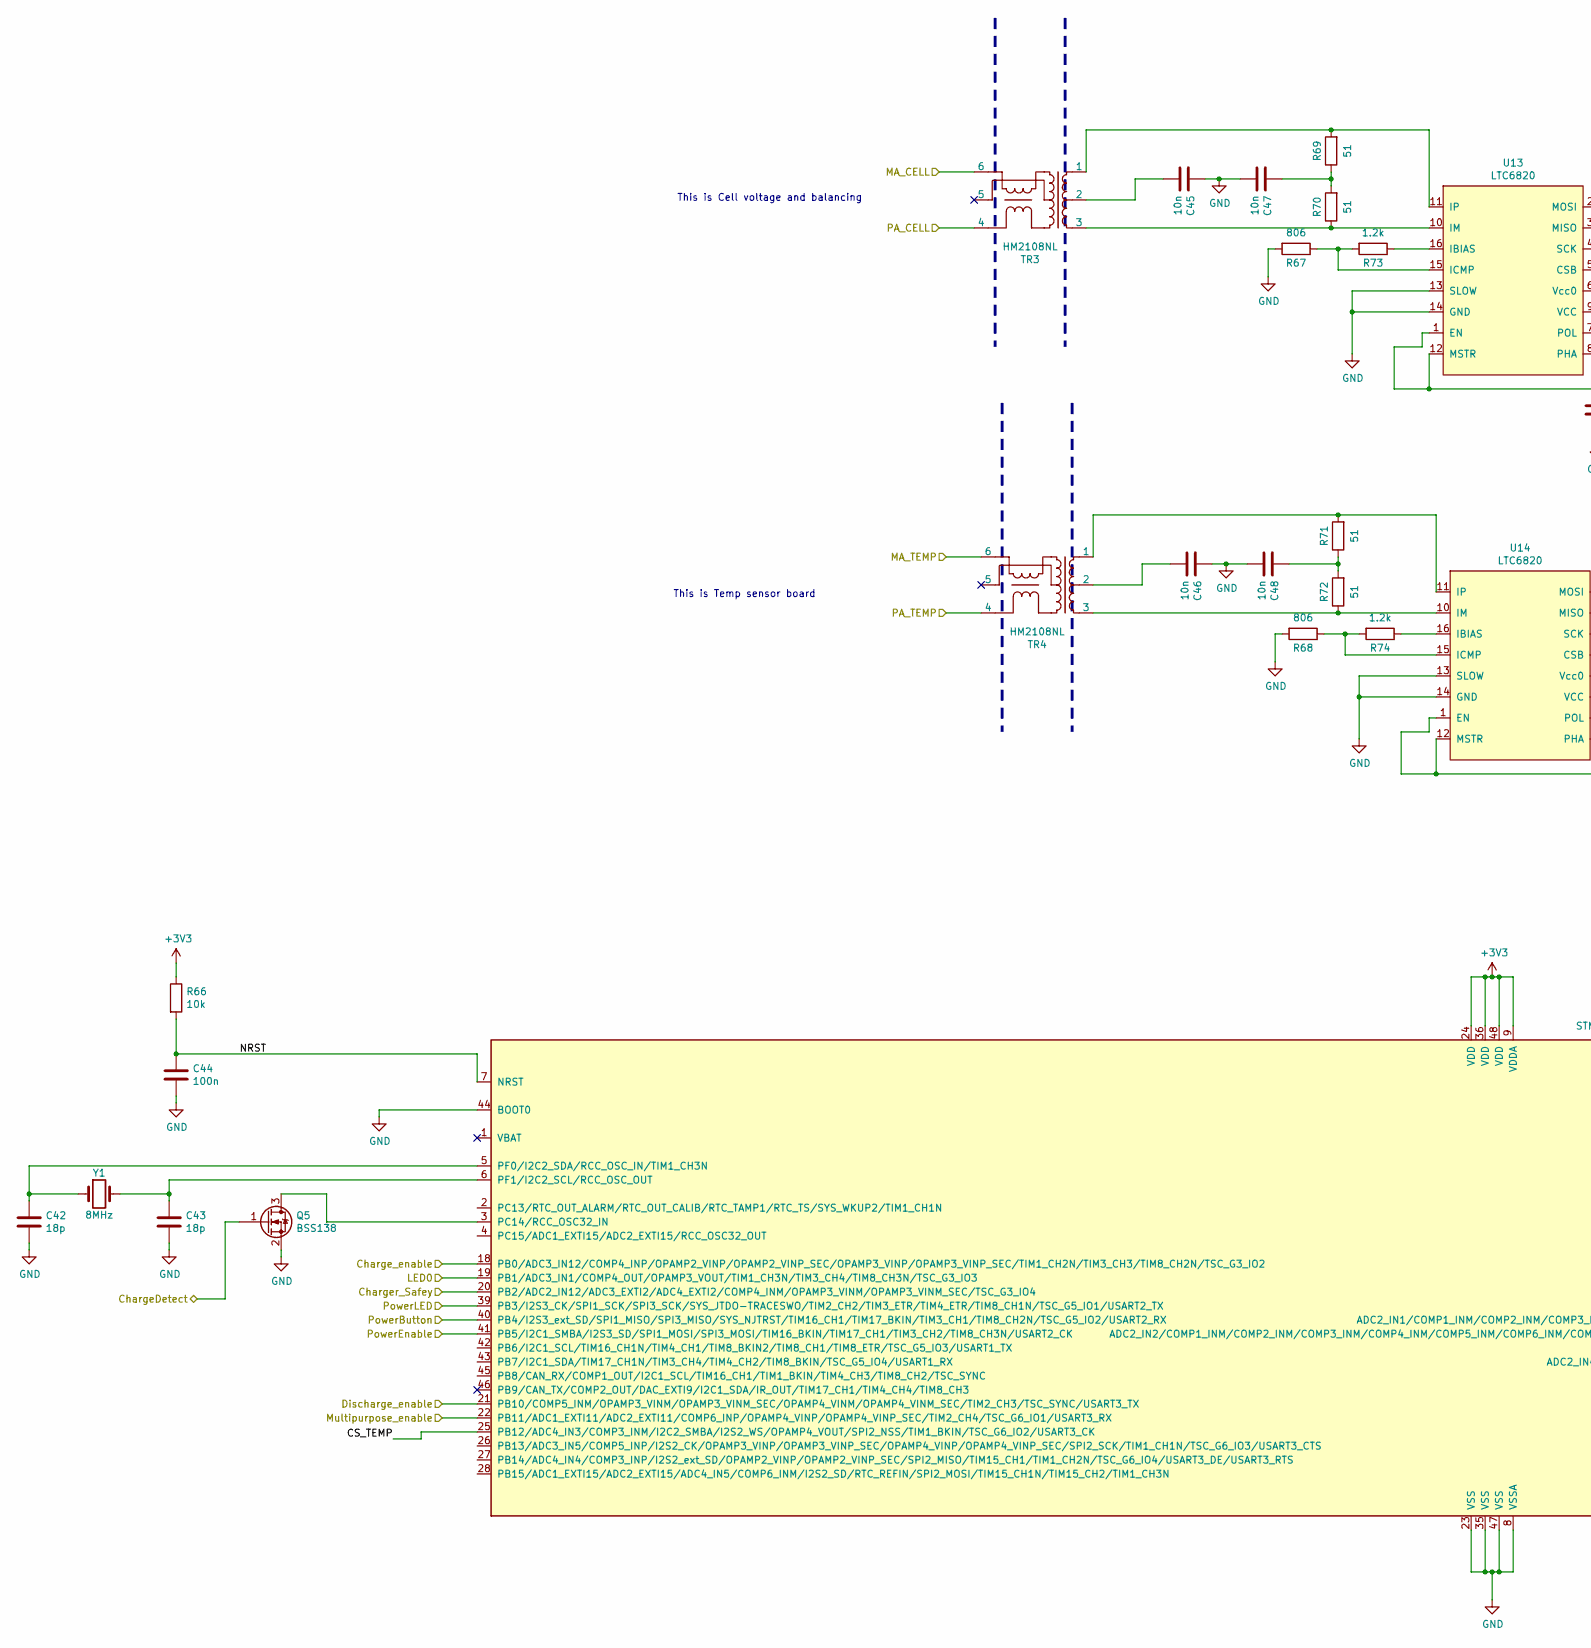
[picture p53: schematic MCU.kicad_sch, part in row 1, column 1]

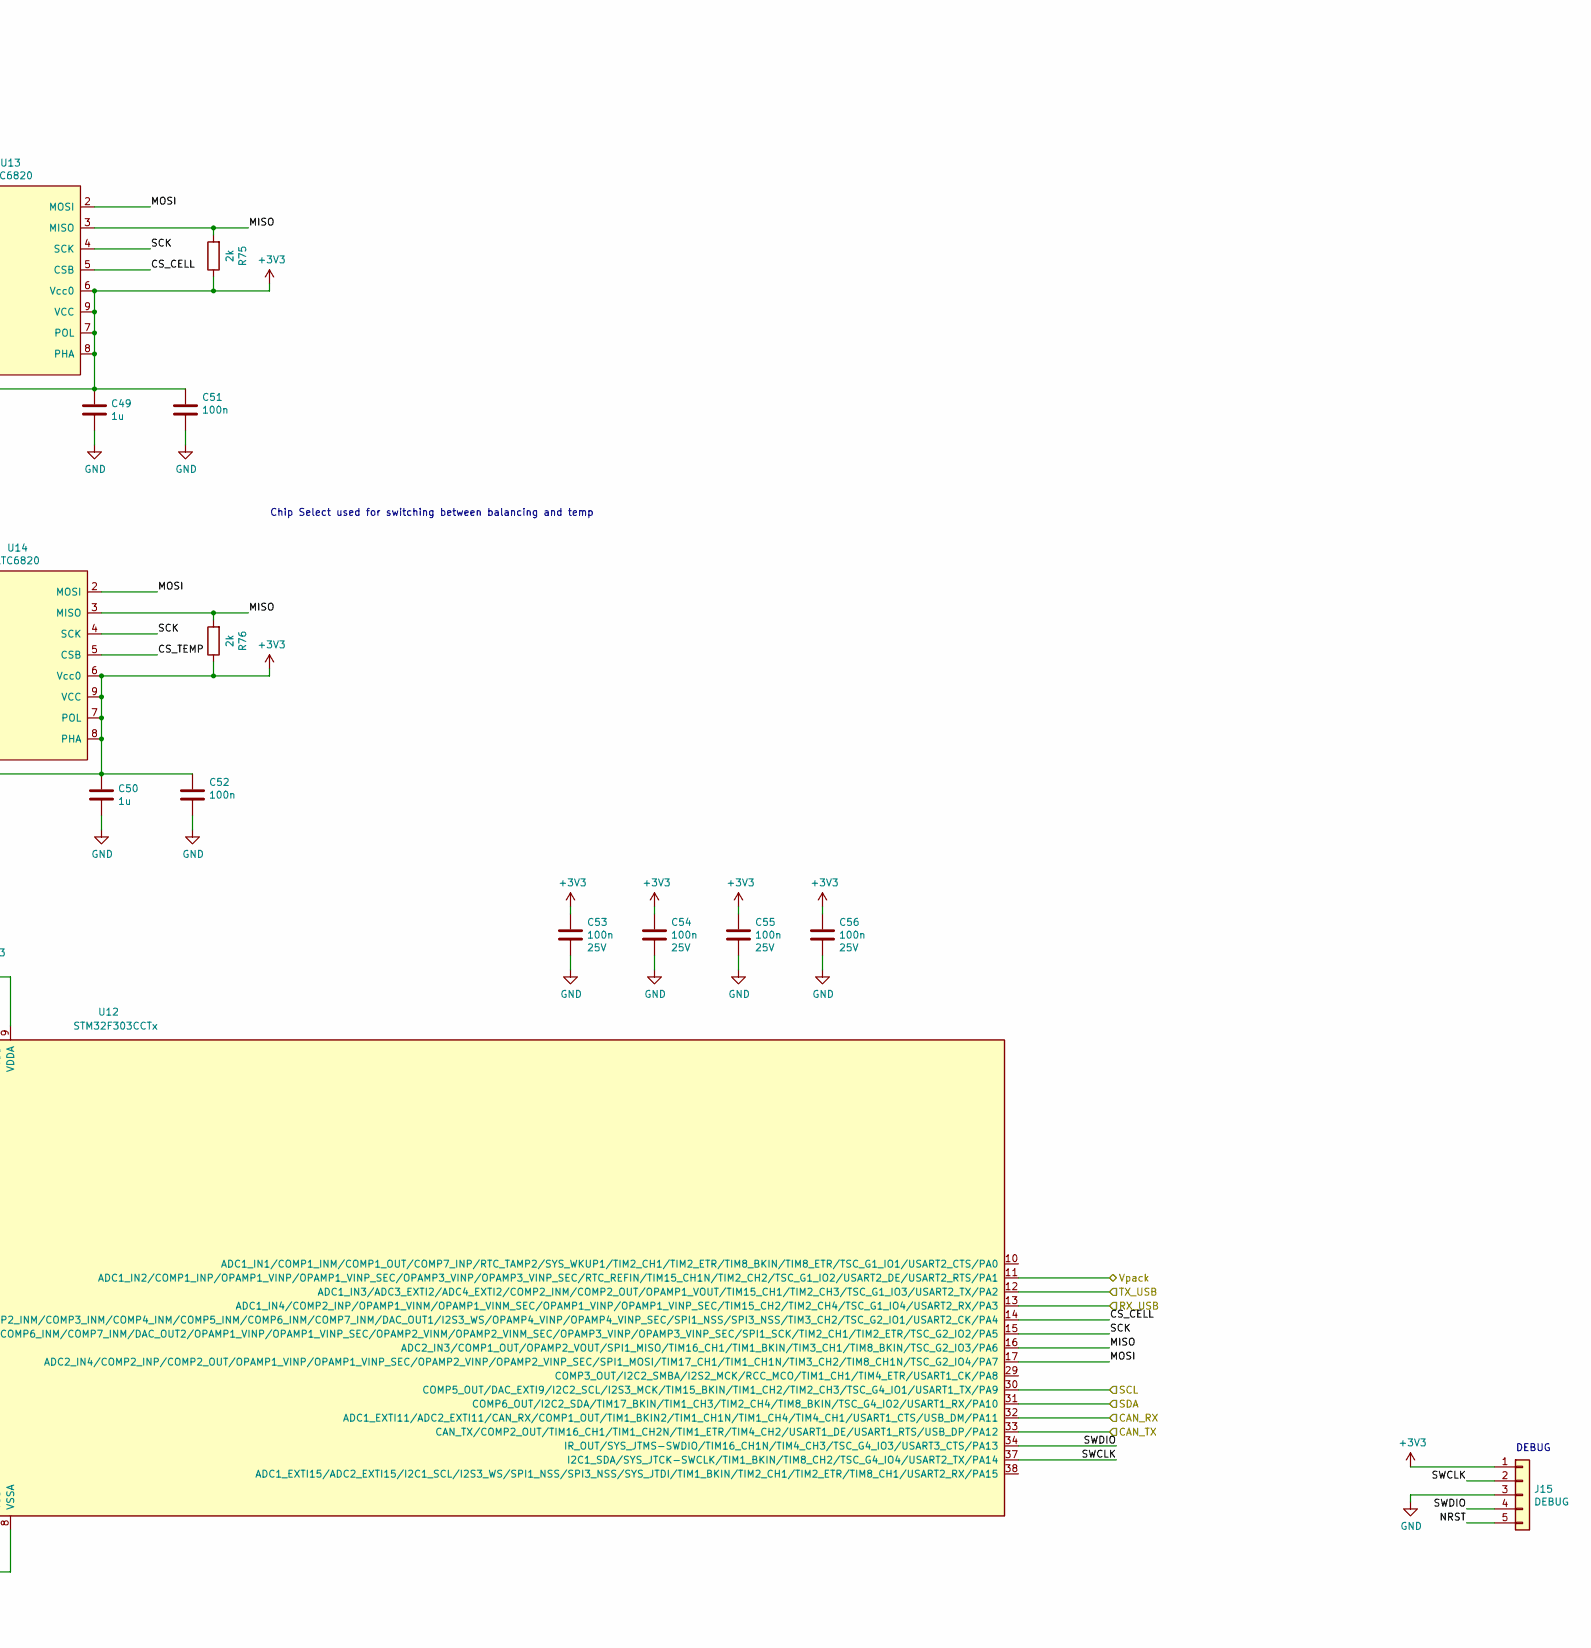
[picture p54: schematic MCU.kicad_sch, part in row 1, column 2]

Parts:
C42, C43: 18p; C_0603_1608Metric; Voltage 50V; MPN GRM1885C1H180JA01D
C44: 100n; C_0603_1608Metric; MPN GRM188R71E104KA01D
C45, C46, C47, C48: 10n; C_0603_1608Metric; MPN 885012206114
C49, C50: 1u; C_0603_1608Metric; MPN GRM188R71E105KA12D
C51, C52, C53, C54, C55, C56: 100n; C_0603_1608Metric; Voltage 25V; MPN GRM188R71E104KA01D
J15: DEBUG; JST_XH_B5B-XH-A_1x05_P2.50mm_Vertical; MPN B5B-XH-A
Q5: BSS138; SOT-23; MPN BSS138
R66: 10k; R_0603_1608Metric; MPN RC0603FR-0710KL
R67, R68: 806; R_0603_1608Metric; MPN RC0603FR-07806RL
R69, R70, R71, R72: 51; R_0603_1608Metric; MPN RC0603JR-0751RL
R73, R74: 1.2k; R_0603_1608Metric; MPN RC0603JR-071K2L
R75, R76: 2k; R_0603_1608Metric; MPN RC0603FR-072KL
TR3, TR4: HM2108NL; MPN HM2108NL
U12: STM32F303CCTx; LQFP-48_7x7mm_P0.5mm; MPN STM32F303CCT6
U13, U14: LTC6820; MSOP-16_3x4.039mm_P0.5mm; MPN LTC6820IMS#PBF
Y1: 8MHz; Crystal_SMD_Abracon_ABM3-2Pin_5.0x3.2mm; MPN ABM3-8.000MHZ-D2Y-T

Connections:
+3V3: C49.2, C50.2, C51.1, C52.1, C53.1, C54.1, C55.1, C56.1, J15.1, R66.1, R75.1, R76.1, U12.9 (VDDA), U12.24 (VDD), U12.36 (VDD), U12.48 (VDD), U13.1 (EN), U13.6 (Vcc0), U13.7 (POL), U13.8 (PHA), U13.9 (VCC), U13.12 (MSTR), U14.1 (EN), U14.6 (Vcc0), U14.7 (POL), U14.8 (PHA), U14.9 (VCC), U14.12 (MSTR); also elsewhere on the board
/BMS_OK/Charge_enable: U12.18 (PB0/ADC3_IN12/COMP4_INP/OPAMP2_VINP/OPA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); also elsewhere on the board
/BMS_OK/Charger_Safey: U12.20 (PB2/ADC2_IN12/ADC3_EXTI2/ADC4_EXTI2/COM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); also elsewhere on the board
/BMS_OK/Discharge_enable: U12.21 (PB10/COMP5_INM/OPAMP3_VINM/OPAMP3_VINM_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); also elsewhere on the board
/BMS_OK/Multipurpose_enable: U12.22 (PB11/ADC1_EXTI11/ADC2_EXTI11/COMP6_INP/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); also elsewhere on the board
/CAN/CAN_RX: U12.32 (ADC1_EXTI11/ADC2_EXTI11/CAN_RX/COMP1_OU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); also elsewhere on the board
/CAN/CAN_TX: U12.33 (CAN_TX/COMP2_OUT/TIM16_CH1/TIM1_CH2N/TI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); also elsewhere on the board
/MCU/CS_CELL: U12.14 (ADC2_IN1/COMP1_INM/COMP2_INM/COMP3_INM/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), U13.5 (CSB)
/MCU/CS_TEMP: U12.25 (PB12/ADC4_IN3/COMP3_INM/I2C2_SMBA/I2S2_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), U14.5 (CSB)
/MCU/LED0: U12.19 (PB1/ADC3_IN1/COMP4_OUT/OPAMP3_VOUT/TIM1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); also elsewhere on the board
/MCU/MA_CELL: TR3.6; also elsewhere on the board
/MCU/MA_TEMP: TR4.6; also elsewhere on the board
/MCU/MISO: R75.2, R76.2, U12.16 (ADC2_IN3/COMP1_OUT/OPAMP2_VOUT/SPI1_MIS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), U13.3 (MISO), U14.3 (MISO)
/MCU/MOSI: U12.17 (ADC2_IN4/COMP2_INP/COMP2_OUT/OPAMP1_VIN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), U13.2 (MOSI), U14.2 (MOSI)
/MCU/NRST: C44.1, J15.5, R66.2, U12.7 (NRST)
/MCU/PA_CELL: TR3.4; also elsewhere on the board
/MCU/PA_TEMP: TR4.4; also elsewhere on the board
/MCU/PowerButton: U12.40 (PB4/I2S3_ext_SD/SPI1_MISO/SPI3_MISO/SYS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); also elsewhere on the board
/MCU/PowerEnable: U12.41 (PB5/I2C1_SMBA/I2S3_SD/SPI1_MOSI/SPI3_MO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); also elsewhere on the board
/MCU/PowerLED: U12.39 (PB3/I2S3_CK/SPI1_SCK/SPI3_SCK/SYS_JTDO-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); also elsewhere on the board
/MCU/RX_USB: U12.13 (ADC1_IN4/COMP2_INP/OPAMP1_VINM/OPAMP1_V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); also elsewhere on the board
/MCU/SCK: U12.15 (ADC2_IN2/COMP1_INM/COMP2_INM/COMP3_INM/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), U13.4 (SCK), U14.4 (SCK)
/MCU/SCL: U12.30 (COMP5_OUT/DAC_EXTI9/I2C2_SCL/I2S3_MCK/T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); also elsewhere on the board
/MCU/SDA: U12.31 (COMP6_OUT/I2C2_SDA/TIM17_BKIN/TIM1_CH3/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); also elsewhere on the board
/MCU/SWCLK: J15.2, U12.37 (I2C1_SDA/SYS_JTCK-SWCLK/TIM1_BKIN/TIM8_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)
/MCU/SWDIO: J15.4, U12.34 (IR_OUT/SYS_JTMS-SWDIO/TIM16_CH1N/TIM4_C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)
/MCU/TX_USB: U12.12 (ADC1_IN3/ADC3_EXTI2/ADC4_EXTI2/COMP2_IN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); also elsewhere on the board
/MCU/Vpack: U12.11 (ADC1_IN2/COMP1_INP/OPAMP1_VINP/OPAMP1_V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); also elsewhere on the board
/PowerSupply/ChargeDetect: Q5.1 (G); also elsewhere on the board
GND: C42.2, C43.2, C44.2, C45.2, C46.2, C47.1, C48.1, C49.1, C50.1, C51.2, C52.2, C53.2, C54.2, C55.2, C56.2, J15.3, Q5.2 (S), R67.2, R68.2, U12.8 (VSSA), U12.23 (VSS), U12.35 (VSS), U12.44 (BOOT0), U12.47 (VSS), U13.13 (SLOW), U13.14 (GND), U14.13 (SLOW), U14.14 (GND); also elsewhere on the board
unnamed: C45.1, TR3.2
unnamed: C46.1, TR4.2
unnamed: C47.2, R69.1, R70.2
unnamed: C48.2, R71.1, R72.2
unnamed: Q5.3 (D), U12.3 (PC14/RCC_OSC32_IN)
unnamed: C42.1, U12.5 (PF0/I2C2_SDA/RCC_OSC_IN/TIM1_CH3N), Y1.1
unnamed: C43.1, U12.6 (PF1/I2C2_SCL/RCC_OSC_OUT), Y1.2
unnamed: R73.1, U13.16 (IBIAS)
unnamed: R67.1, R73.2, U13.15 (ICMP)
unnamed: R70.1, TR3.3, U13.10 (IM)
unnamed: R69.2, TR3.1, U13.11 (IP)
unnamed: R74.1, U14.16 (IBIAS)
unnamed: R68.1, R74.2, U14.15 (ICMP)
unnamed: R72.1, TR4.3, U14.10 (IM)
unnamed: R71.2, TR4.1, U14.11 (IP)

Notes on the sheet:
This is Temp sensor board
Chip Select used for switching between balancing and temp
This is Cell voltage and balancing
DEBUG

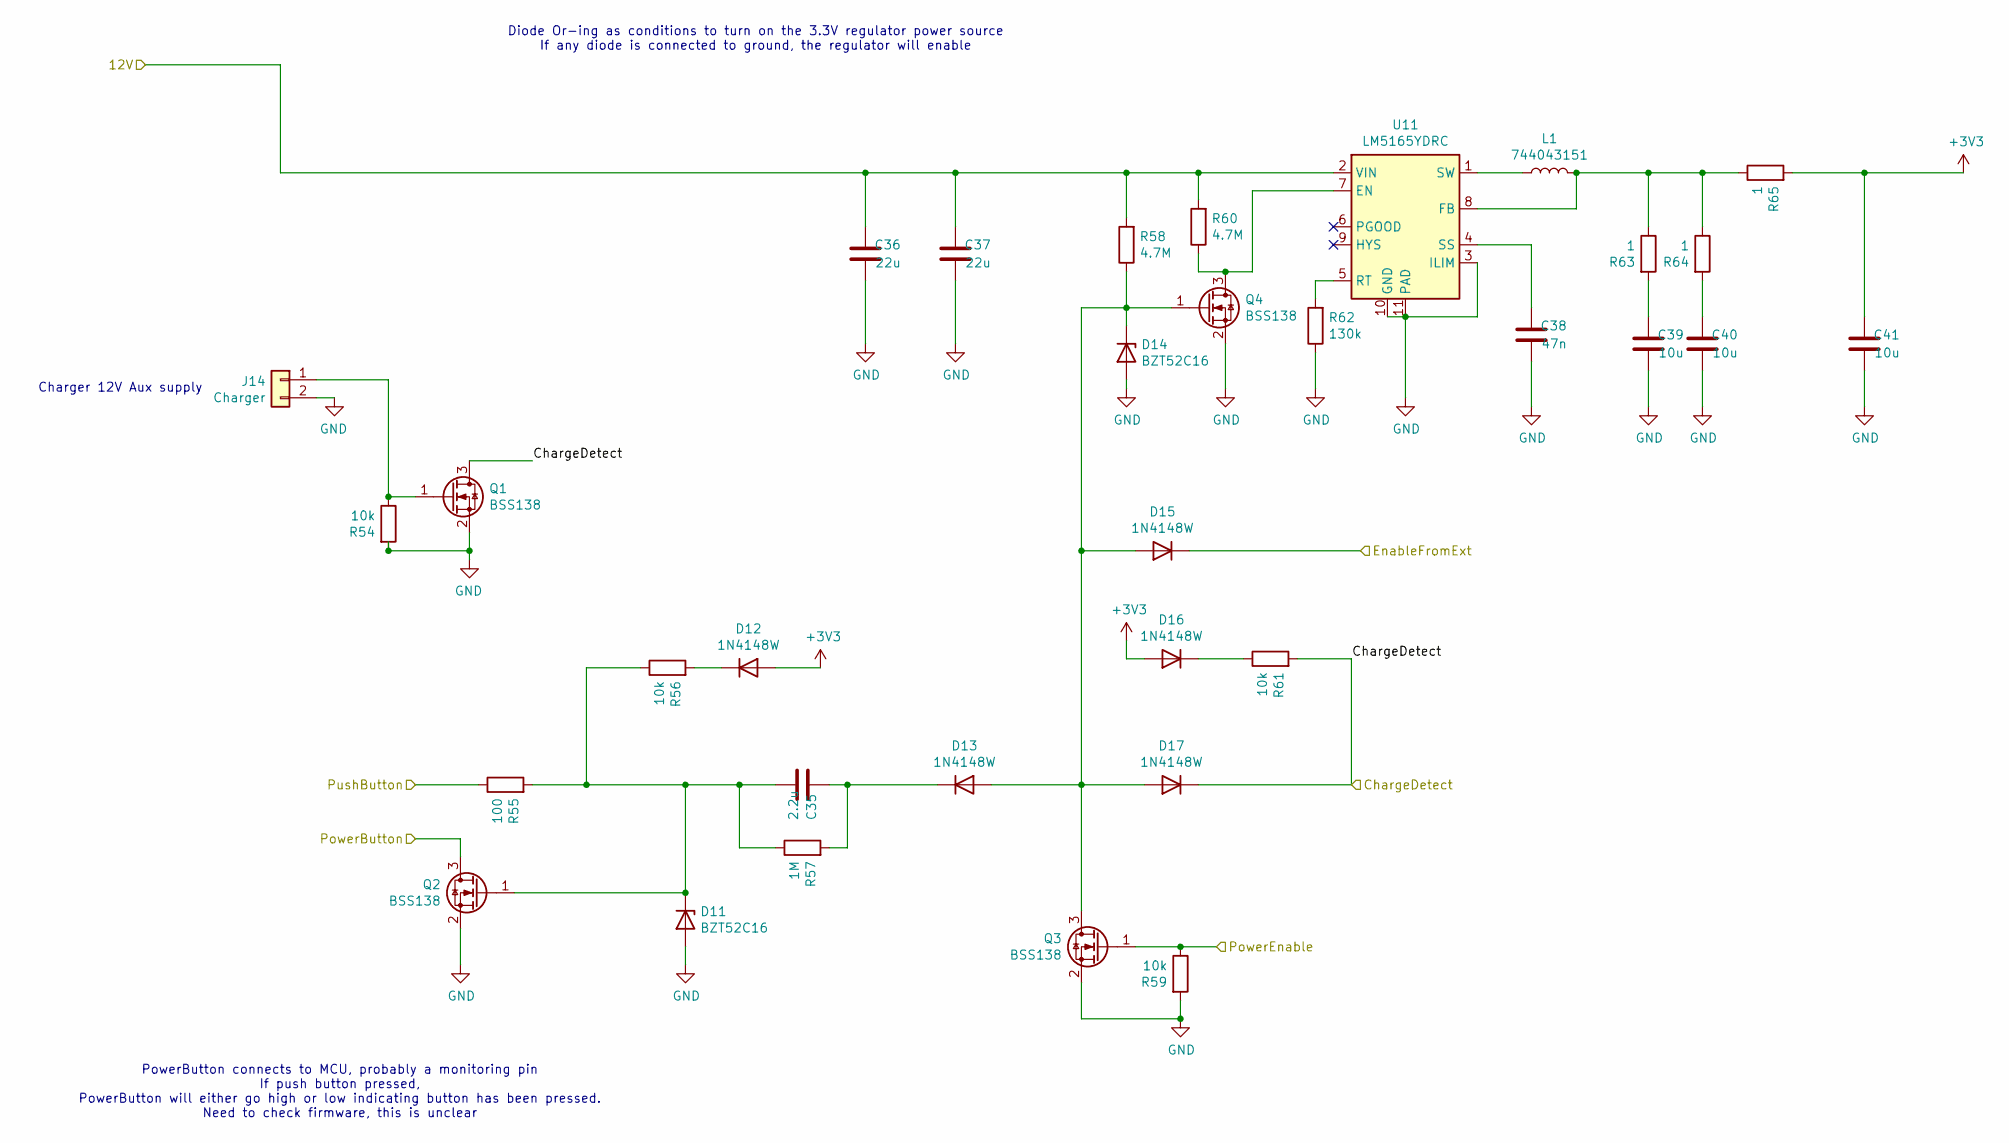
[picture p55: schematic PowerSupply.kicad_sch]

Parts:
C35: 2.2u; C_0603_1608Metric; MPN GRM188R61A225KE34D
C36, C37: 22u; C_0805_2012Metric; MPN CL21A226MOQNNNE
C38: 47n; C_0603_1608Metric; Voltage 100V; MPN GCM188R71H473KA55D
C39, C40, C41: 10u; C_0603_1608Metric; MPN CL10A106MQ8NNNC
D11, D14: BZT52C16; D_SOD-123; MPN BZT52C16-E3-08
D12, D13, D15, D16, D17: 1N4148W; D_SOD-123; MPN 1N4148W-7-F
J14: Charger; JST_XH_B2B-XH-A_1x02_P2.50mm_Vertical; MPN B2B-XH-A
L1: 744043151; L_Wuerth_WE-PD2-Typ-MS; MPN 744043151
Q1, Q2, Q3, Q4: BSS138; SOT-23; MPN BSS138
R54, R56, R59, R61: 10k; R_0603_1608Metric; MPN RC0603FR-0710KL
R55: 100; R_0603_1608Metric; MPN RC0603FR-07100RL
R57: 1M; R_0603_1608Metric; MPN RC0603JR-071ML
R58, R60: 4.7M; R_0603_1608Metric; MPN RC0603FR-074M7L
R62: 130k; R_0603_1608Metric; MPN RC0603FR-07130KL
R63, R64, R65: 1; R_0603_1608Metric; MPN RC0603FR-071RL
U11: LM5165YDRC; Texas_S-PVSON-N10_ThermalVias; MPN LM5165YDRCT

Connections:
+3V3: C41.2, D12.2 (A), D16.2 (A), R65.2; also elsewhere on the board
+12V: C36.2, C37.2, R58.2, R60.2, U11.2 (VIN); also elsewhere on the board
/CAN/EnableRequest: D15.1 (K); also elsewhere on the board
/MCU/PowerButton: Q2.3 (D); also elsewhere on the board
/MCU/PowerEnable: Q3.1 (G), R59.1; also elsewhere on the board
/PowerSupply/ChargeDetect: D17.1 (K), Q1.3 (D), R61.2; also elsewhere on the board
/PowerSupply/PushButton: R55.1; also elsewhere on the board
GND: C36.1, C37.1, C38.1, C39.1, C40.1, C41.1, D11.2 (A), D14.2 (A), J14.2, Q1.2 (S), Q2.2 (S), Q3.2 (S), Q4.2 (S), R54.2, R59.2, R62.1, U11.3 (ILIM), U11.10 (GND), U11.11 (PAD); also elsewhere on the board
unnamed: C39.2, R63.2
unnamed: C40.2, R64.2
unnamed: C35.1, D11.1 (K), Q2.1 (G), R55.2, R56.1, R57.1
unnamed: D12.1 (K), R56.2
unnamed: D13.2 (A), D14.1 (K), D15.2 (A), D17.2 (A), Q3.3 (D), Q4.1 (G), R58.1
unnamed: C35.2, D13.1 (K), R57.2
unnamed: D16.1 (K), R61.1
unnamed: J14.1, Q1.1 (G), R54.1
unnamed: Q4.3 (D), R60.1, U11.7 (EN)
unnamed: L1.2, R63.1, R64.1, R65.1, U11.8 (FB)
unnamed: R62.2, U11.5 (RT)
unnamed: C38.2, U11.4 (SS)
unnamed: L1.1, U11.1 (SW)

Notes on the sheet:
Diode Or-ing as conditions to turn on the 3.3V regulator power source If any diode is connected to ground, the regulator will enable
PowerButton connects to MCU, probably a monitoring pin If push button pressed, PowerButton will either go high or low indicating button has been pressed. Need to check firmware, this is unclear
Charger 12V Aux supply

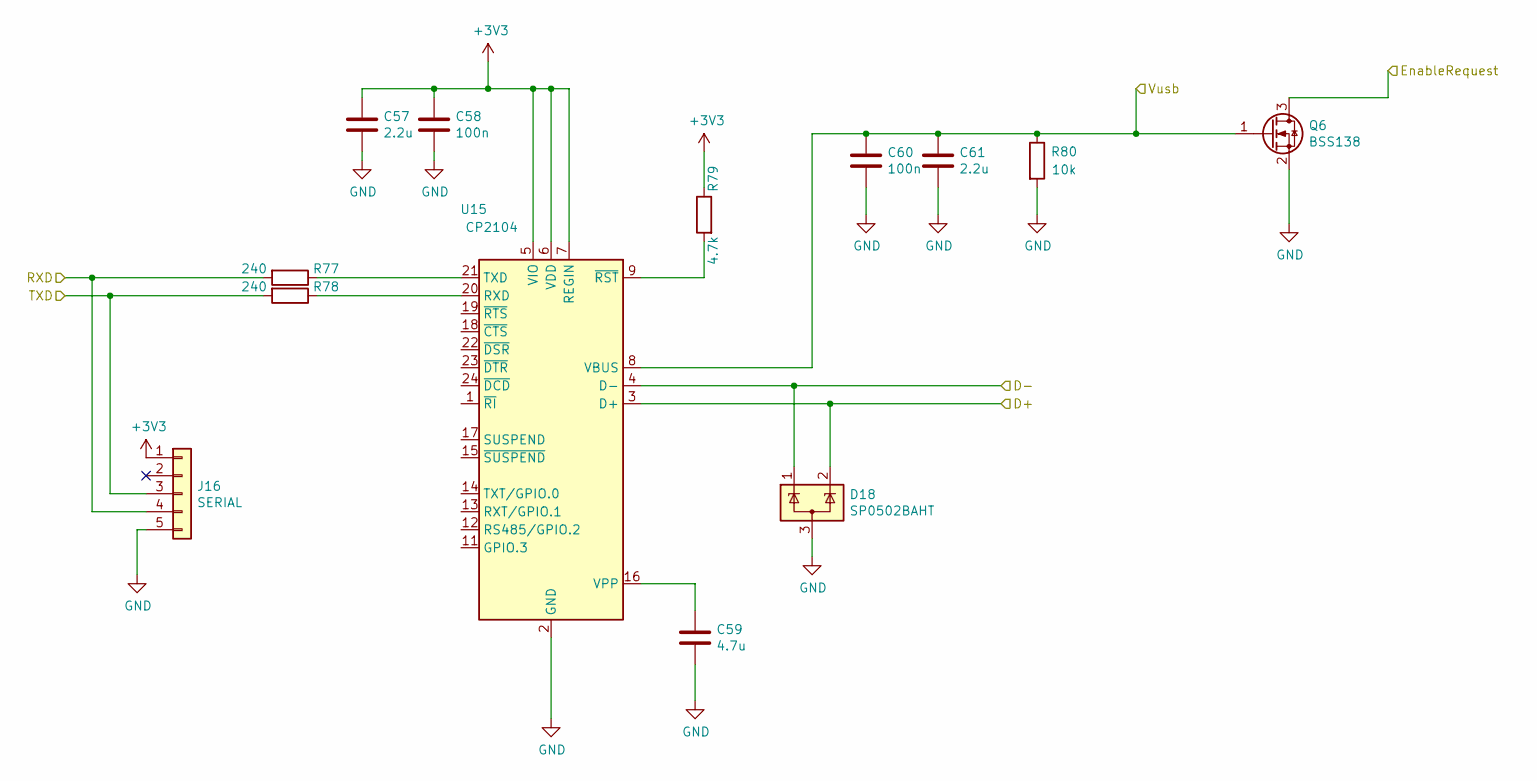
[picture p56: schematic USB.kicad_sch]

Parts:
C57, C61: 2.2u; C_0603_1608Metric; MPN GRM188R61A225KE34D
C58, C60: 100n; C_0603_1608Metric; MPN GRM188R71E104KA01D
C59: 4.7u; C_0603_1608Metric; MPN GRM188Z71A475ME15D
D18: SP0502BAHT; SOT-23; MPN SP0502BAHTG
J16: SERIAL; JST_XH_B5B-XH-A_1x05_P2.50mm_Vertical; MPN B5B-XH-A
Q6: BSS138; SOT-23; MPN BSS138
R77, R78: 240; R_0603_1608Metric; MPN RC0603FR-07240RL
R79: 4.7k; R_0603_1608Metric; MPN RC0603JR-074K7L
R80: 10k; R_0603_1608Metric; MPN RC0603FR-0710KL
U15: CP2104; QFN-24-1EP_4x4mm_P0.5mm_EP2.7x2.7mm; MPN CP2104-F03-GM

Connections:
+3V3: C57.1, C58.1, J16.1, R79.1, U15.5 (VIO), U15.6 (VDD), U15.7 (REGIN); also elsewhere on the board
/CAN/EnableRequest: Q6.3 (D); also elsewhere on the board
/MCU/RX_USB: J16.4, R77.2; also elsewhere on the board
/MCU/TX_USB: J16.3, R78.2; also elsewhere on the board
/USB/D+: D18.2 (K), U15.3 (D+); also elsewhere on the board
/USB/D-: D18.1 (K), U15.4 (D-); also elsewhere on the board
/USB/Vusb: C60.1, C61.1, Q6.1 (G), R80.1, U15.8 (VBUS); also elsewhere on the board
GND: C57.2, C58.2, C59.2, C60.2, C61.2, D18.3 (A), J16.5, Q6.2 (S), R80.2, U15.2 (GND), U15.25 (GND); also elsewhere on the board
unnamed: R78.1, U15.20 (RXD)
unnamed: R77.1, U15.21 (TXD)
unnamed: C59.1, U15.16 (VPP)
unnamed: R79.2, U15.9 (~RST)

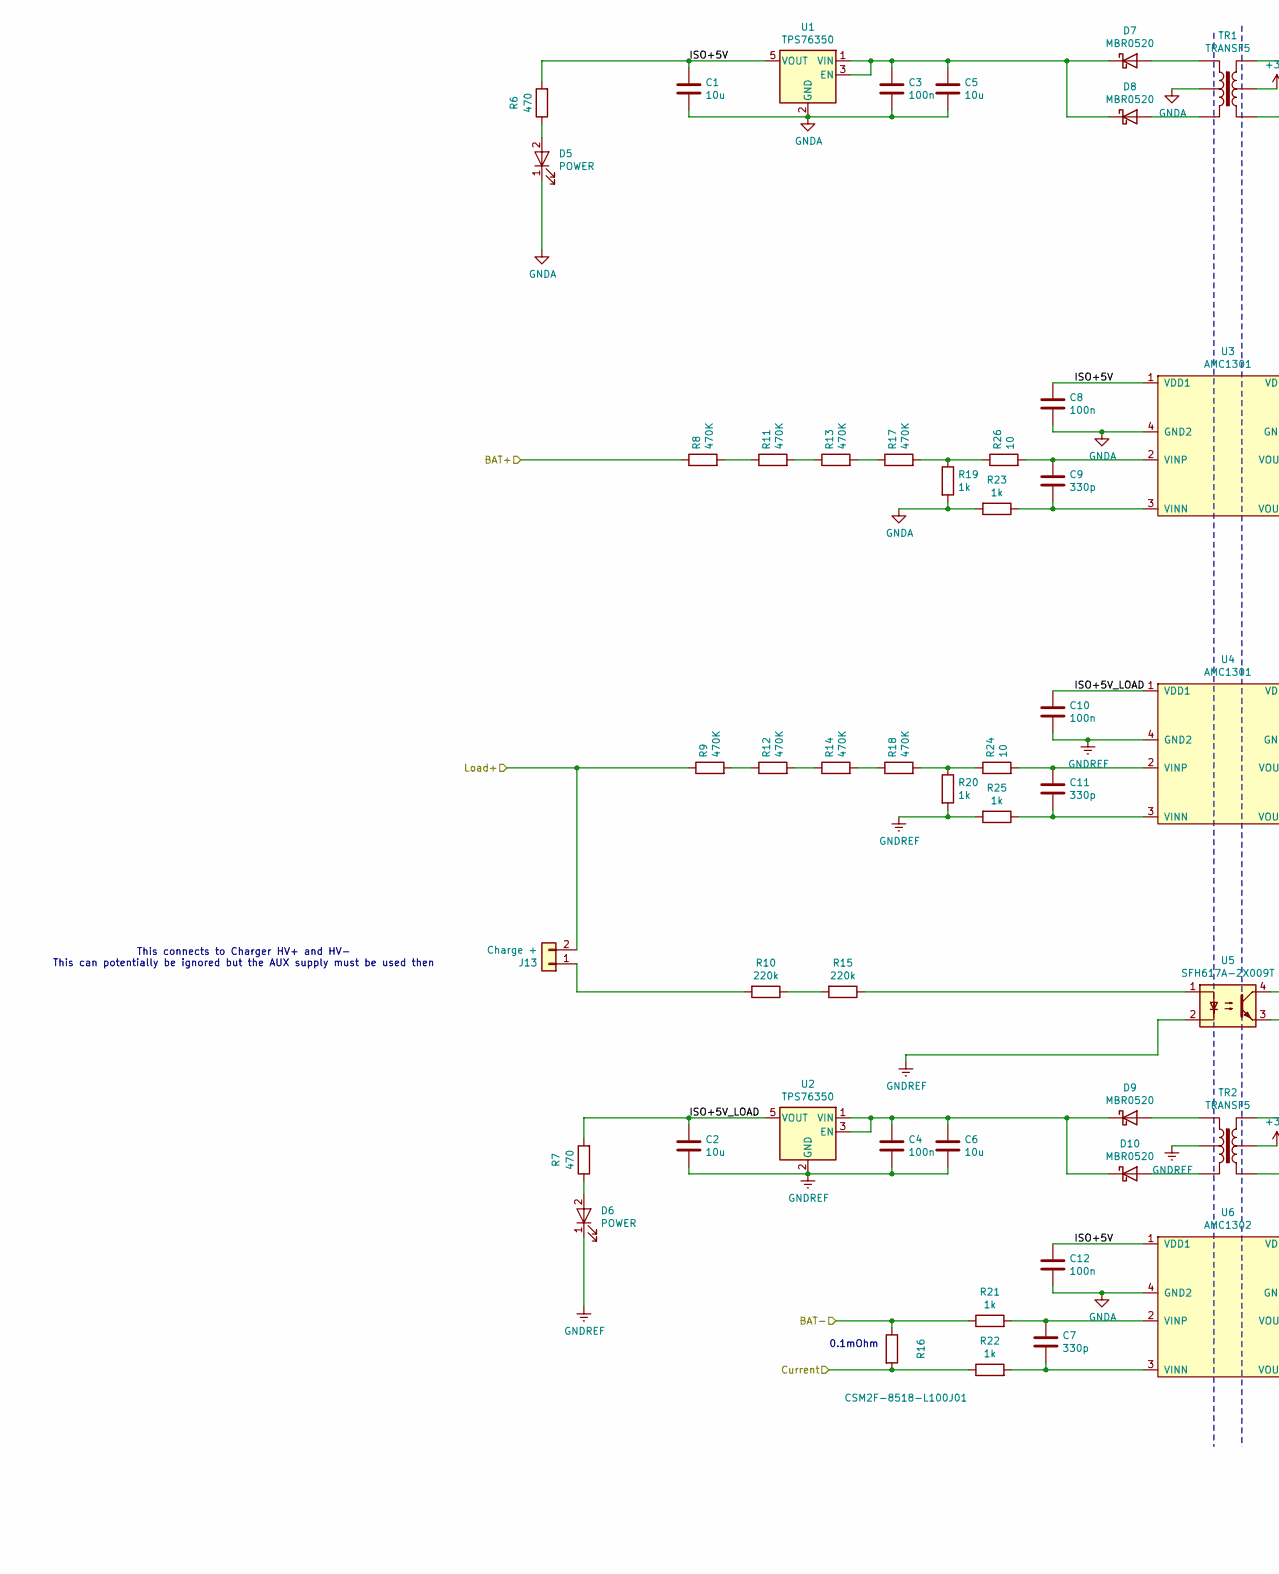
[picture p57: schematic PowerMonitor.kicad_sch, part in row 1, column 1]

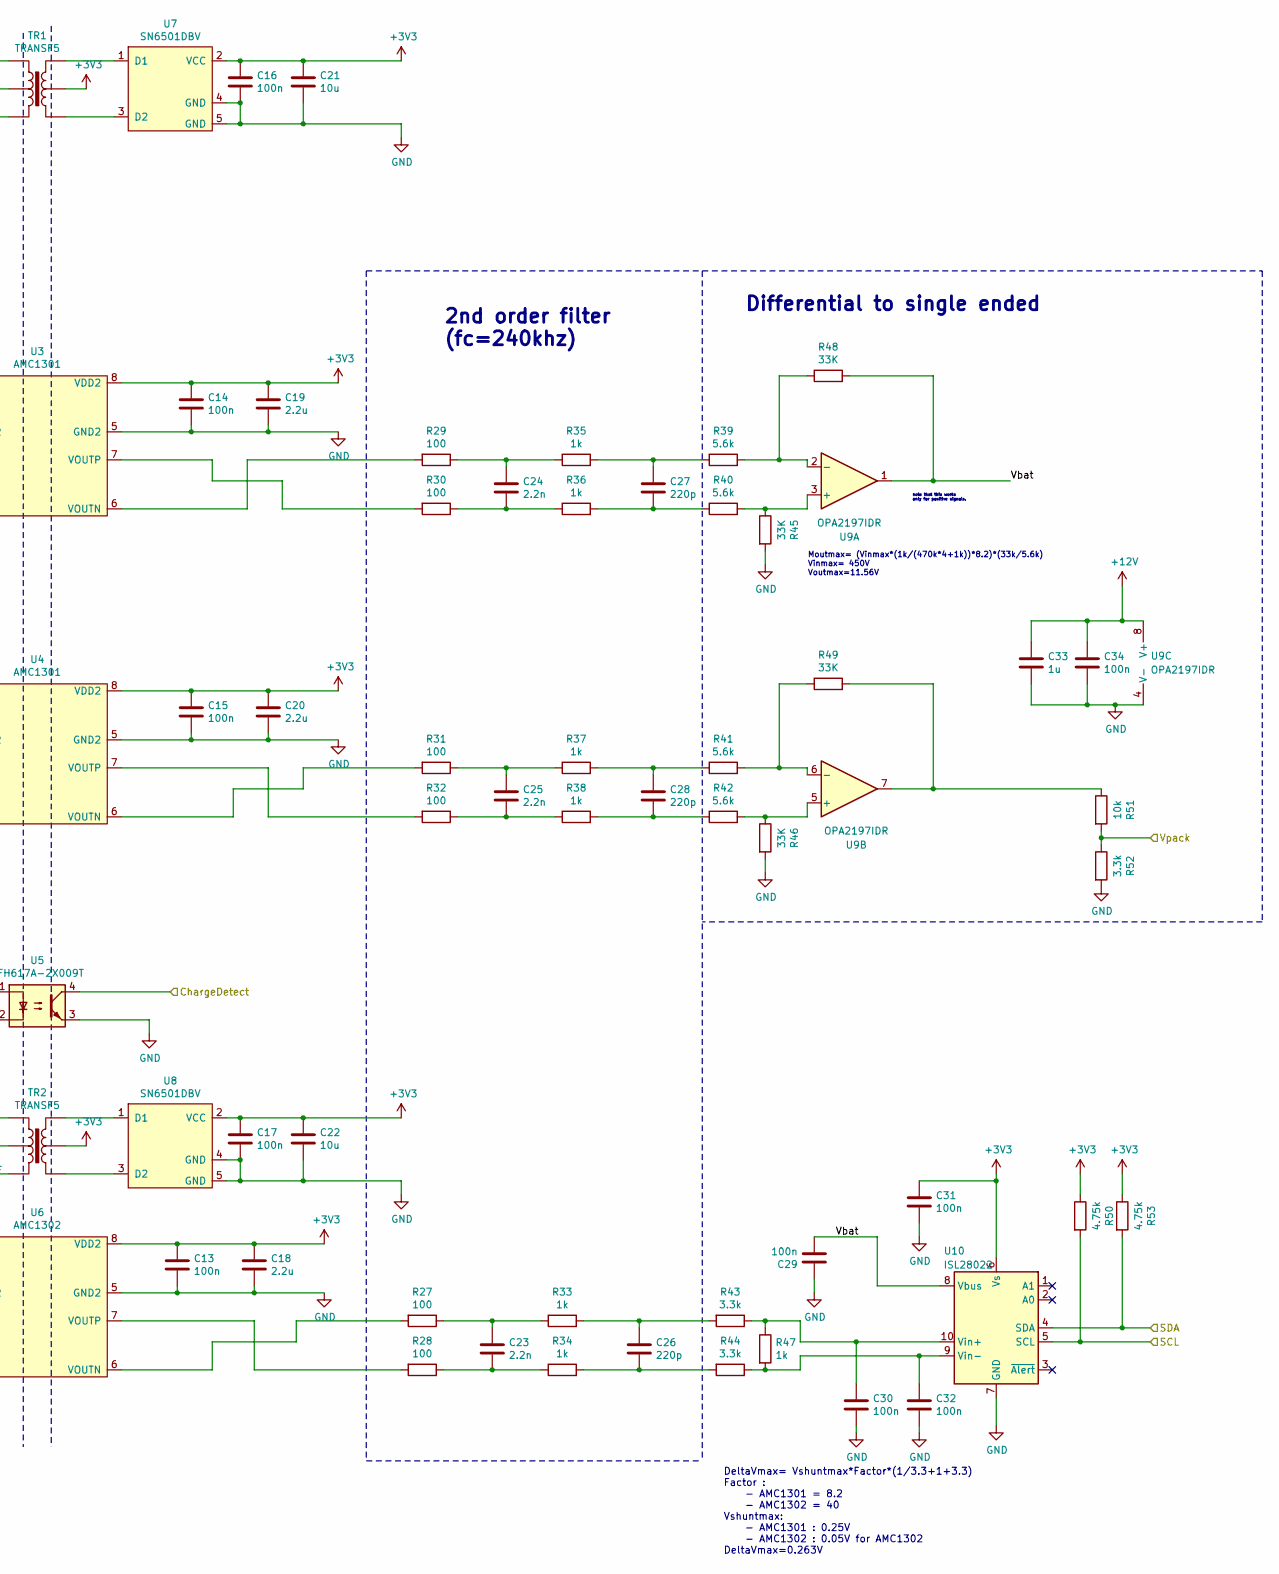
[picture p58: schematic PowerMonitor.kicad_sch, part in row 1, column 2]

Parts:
C1, C2, C5, C6: 10u; C_0805_2012Metric; MPN CL21A106KAYNNNE
C3, C4, C8, C10, C12, C13, C14, C15, C16, C17, C29, C30, C31, C32, C34: 100n; C_0603_1608Metric; MPN GRM188R71E104KA01D
C7, C9, C11: 330p; C_0603_1608Metric; MPN CL10B331KB8NNNC
C18, C19, C20: 2.2u; C_0603_1608Metric; MPN GRM188R61A225KE34D
C21, C22: 10u; C_0603_1608Metric; MPN CL10A106MQ8NNNC
C23, C24, C25: 2.2n; C_0603_1608Metric; MPN GRM1885C1H222JA01D
C26, C27, C28: 220p; C_0603_1608Metric; MPN GRM1555C1H221JA01D
C33: 1u; C_0603_1608Metric; MPN GRM188R71E105KA12D
D5, D6: POWER; LED_0603_1608Metric; MPN SML-D12P8WT86C
D7, D8, D9, D10: MBR0520; D_SOD-123; MPN MBR0502L
J13: Charge +; Phoenix_1x2_1729128; MPN 1729128
R6, R7: 470; R_0603_1608Metric; MPN RC0603JR-07470RL
R8, R9, R11, R12, R13, R14, R17, R18: 470K; R_1206_3216Metric; MPN RC1206FR-07470KL
R10, R15: 220k; R_2512_6332Metric; MPN CRCW2512220KFKEG
R16: CSM2F-8518-L100J01; MPN CSM2F-8518-L100J01
R19, R20, R21, R22, R23, R25, R33, R34, R35, R36, R37, R38, R47: 1k; R_0603_1608Metric; MPN MCWR06X1001FTL
R24, R26: 10; R_0603_1608Metric; MPN RC0603JR-0710RL
R27, R28, R29, R30, R31, R32: 100; R_0603_1608Metric; MPN RC0603FR-07100RL
R39, R40, R41, R42: 5.6k; R_0603_1608Metric; MPN RC0603JR-075K6L
R43, R44, R52: 3.3k; R_0603_1608Metric; MPN RC0603FR-073K3L
R45, R46, R48, R49: 33K; R_0603_1608Metric; MPN RC0603FR-0733KL
R50, R53: 4.75k; R_0603_1608Metric; MPN RC0603JR-074K7L
R51: 10k; R_0603_1608Metric; MPN RC0603FR-0710KL
TR1, TR2: TRANSF5; WURTH-760390014; MPN 760390014
U1, U2: TPS76350; SOT-23-5; MPN TPS76350DBVR
U3, U4: AMC1301; SSO-8_6.8x5.9mm_Pitch1.27mm_Clearance8mm; MPN AMC1301DWV
U5: SFH617A-2X009T; SMDIP-4_W9.53mm_Clearance8mm; MPN SFH617A-2X009T
U6: AMC1302; SSO-8_6.8x5.9mm_Pitch1.27mm_Clearance8mm; MPN AMC1302
U7, U8: SN6501DBV; SOT-23-5; MPN SN6501DBVR
U9: OPA2197IDR; SOIC-8_3.9x4.9mm_P1.27mm; MPN OPA2197IDR
U10: ISL28022; MSOP-10_3x3mm_P0.5mm; MPN ISL28022FUZ-T7A

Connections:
+3V3: C13.1, C14.1, C15.1, C16.1, C17.1, C18.1, C19.1, C20.1, C21.1, C22.1, C31.2, R50.1, R53.1, TR1.5, TR2.5, U3.8 (VDD2), U4.8 (VDD2), U6.8 (VDD2), U7.2 (VCC), U8.2 (VCC), U10.6 (Vs); also elsewhere on the board
+12V: C33.1, C34.1, U9.8 (V+); also elsewhere on the board
/BAT+: R8.1; also elsewhere on the board
/Load+: J13.2, R9.1; also elsewhere on the board
/MCU/SCL: R50.2, U10.5 (SCL); also elsewhere on the board
/MCU/SDA: R53.2, U10.4 (SDA); also elsewhere on the board
/MCU/Vpack: R51.2, R52.1; also elsewhere on the board
/PowerMonitor/Current: R16.2, R22.1; also elsewhere on the board
/PowerMonitor/ISO+5V: C1.1, C8.1, C12.1, R6.2, U1.5 (VOUT), U3.1 (VDD1), U6.1 (VDD1)
/PowerMonitor/ISO+5V_LOAD: C2.1, C10.1, R7.2, U2.5 (VOUT), U4.1 (VDD1)
/PowerMonitor/Vbat: C29.1, R48.2, U9.1, U10.8 (Vbus)
/PowerSupply/ChargeDetect: U5.4; also elsewhere on the board
GND: C13.2, C14.2, C15.2, C16.2, C17.2, C18.2, C19.2, C20.2, C21.2, C22.2, C29.2, C30.1, C31.1, C32.1, C33.2, C34.2, R45.2, R46.2, R52.2, U3.5 (GND2), U4.5 (GND2), U5.3, U6.5 (GND2), U7.4 (GND), U7.5 (GND), U8.4 (GND), U8.5 (GND), U9.4 (V-), U10.7 (GND); also elsewhere on the board
GNDA: C1.2, C3.2, C5.2, C8.2, C12.2, D5.1 (K), R16.1, R19.2, R21.1, R23.2, TR1.2, U1.2 (GND), U3.4 (GND2), U6.4 (GND2); also elsewhere on the board
GNDREF: C2.2, C4.2, C6.2, C10.2, D6.1 (K), R20.2, R25.2, TR2.2, U2.2 (GND), U4.4 (GND2), U5.2; also elsewhere on the board
unnamed: C23.1, R27.1, R33.1
unnamed: C23.2, R28.1, R34.1
unnamed: C24.1, R29.1, R35.1
unnamed: C24.2, R30.1, R36.1
unnamed: C25.1, R31.1, R37.1
unnamed: C25.2, R32.1, R38.1
unnamed: C26.1, R33.2, R43.2
unnamed: C26.2, R34.2, R44.2
unnamed: C27.1, R35.2, R39.1
unnamed: C27.2, R36.2, R40.1
unnamed: C28.1, R37.2, R41.1
unnamed: C28.2, R38.2, R42.1
unnamed: D5.2 (A), R6.1
unnamed: D6.2 (A), R7.1
unnamed: D7.2 (A), TR1.1
unnamed: C3.1, C5.1, D7.1 (K), D8.1 (K), U1.1 (VIN), U1.3 (EN)
unnamed: D8.2 (A), TR1.3
unnamed: D9.2 (A), TR2.1
unnamed: D10.2 (A), TR2.3
unnamed: C4.1, C6.1, D9.1 (K), D10.1 (K), U2.1 (VIN), U2.3 (EN)
unnamed: J13.1, R10.2
unnamed: R10.1, R15.2
unnamed: R8.2, R11.1
unnamed: R11.2, R13.1
unnamed: R9.2, R12.1
unnamed: R12.2, R14.1
unnamed: R13.2, R17.1
unnamed: R14.2, R18.1
unnamed: R15.1, U5.1
unnamed: R17.2, R19.1, R26.1
unnamed: R18.2, R20.1, R24.1
unnamed: R49.2, R51.1, U9.7
unnamed: C9.2, R23.1, U3.3 (VINN)
unnamed: C9.1, R26.2, U3.2 (VINP)
unnamed: R29.2, U3.6 (VOUTN)
unnamed: R30.2, U3.7 (VOUTP)
unnamed: C11.2, R25.1, U4.3 (VINN)
unnamed: C11.1, R24.2, U4.2 (VINP)
unnamed: R31.2, U4.6 (VOUTN)
unnamed: R32.2, U4.7 (VOUTP)
unnamed: C7.2, R22.2, U6.3 (VINN)
unnamed: C7.1, R21.2, U6.2 (VINP)
unnamed: R27.2, U6.6 (VOUTN)
unnamed: R28.2, U6.7 (VOUTP)
unnamed: TR1.6, U7.1 (D1)
unnamed: TR1.4, U7.3 (D2)
unnamed: TR2.6, U8.1 (D1)
unnamed: TR2.4, U8.3 (D2)
unnamed: R40.2, R45.1, U9.3 (+)
unnamed: R39.2, R48.1, U9.2 (-)
unnamed: R42.2, R46.1, U9.5 (+)
unnamed: R41.2, R49.1, U9.6 (-)
unnamed: C30.2, R43.1, R47.1, U10.10 (Vin+)
unnamed: C32.2, R44.1, R47.2, U10.9 (Vin-)

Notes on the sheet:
Moutmax= (Vinmax*(1k/(470k*4+1k))*8.2)*(33k/5.6k) Vinmax= 450V Voutmax=11.56V
0.1mOhm
note that this works only for positive signals.
Differential to single ended
This connects to Charger HV+ and HV- This can potentially be ignored but the AUX supply must be used then
DeltaVmax= Vshuntmax*Factor*(1/3.3+1+3.3) Factor : - AMC1301 = 8.2 - AMC1302 = 40 Vshuntmax: - AMC1301 : 0.25V - AMC1302 : 0.05V for AMC1302 DeltaVmax=0.263V
2nd order filter (fc=240khz)


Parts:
Q7, Q8, Q9, Q10: BSS138; SOT-23; MPN BSS138
R81, R82, R83, R84: 10; R_0603_1608Metric; MPN RC0603JR-0710RL

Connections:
/BMS_OK/Charge_enable: R81.1; also elsewhere on the board
/BMS_OK/Charge_enable_S: Q7.3 (D); also elsewhere on the board
/BMS_OK/Charger_Safety_S: Q8.3 (D); also elsewhere on the board
/BMS_OK/Charger_Safey: R82.1; also elsewhere on the board
/BMS_OK/Discharge_enable: R83.1; also elsewhere on the board
/BMS_OK/Discharge_enable_S: Q9.3 (D); also elsewhere on the board
/BMS_OK/Multipurpose_enable: R84.1; also elsewhere on the board
/BMS_OK/Multipurpose_enable_S: Q10.3 (D); also elsewhere on the board
GND: Q7.2 (S), Q8.2 (S), Q9.2 (S), Q10.2 (S); also elsewhere on the board
unnamed: Q7.1 (G), R81.2
unnamed: Q8.1 (G), R82.2
unnamed: Q9.1 (G), R83.2
unnamed: Q10.1 (G), R84.2

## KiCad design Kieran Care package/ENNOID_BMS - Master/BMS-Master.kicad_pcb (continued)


Board: 2 copper layers, 135.1 x 159.4 mm, 218 parts (1 on the bottom side), 149 nets.

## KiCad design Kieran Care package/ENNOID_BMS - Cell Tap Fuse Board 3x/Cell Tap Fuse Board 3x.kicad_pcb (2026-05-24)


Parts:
F1, F3: C308F-V-250MA-TR1; MPN C308F-V-250MA-TR1
H1, H3: MountingHole_Pad; MountingHole_5.5mm_Pad
J1, J3: Conn_01x02; Molex_PicoBlade_53047-0210_1x02_P1.25mm_Vertical; MPN 53047-0210

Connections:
unnamed: F1.1, H1.1
unnamed: F3.1, H3.1
unnamed: F1.2, J1.1
unnamed: F3.2, J3.1


Board: 2 copper layers, 30.0 x 60.0 mm, 6 parts (0 on the bottom side), 4 nets.

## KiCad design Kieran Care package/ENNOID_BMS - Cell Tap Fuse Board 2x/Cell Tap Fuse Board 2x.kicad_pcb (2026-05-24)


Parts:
F5: C308F-V-250MA-TR1; MPN C308F-V-250MA-TR1
H5: MountingHole_Pad; MountingHole_5.5mm_Pad
J5: Conn_01x02; Molex_PicoBlade_53047-0210_1x02_P1.25mm_Vertical; MPN 53047-0210

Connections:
unnamed: F5.1, H5.1
unnamed: F5.2, J5.1


Board: 2 copper layers, 30.0 x 40.1 mm, 3 parts (0 on the bottom side), 2 nets.

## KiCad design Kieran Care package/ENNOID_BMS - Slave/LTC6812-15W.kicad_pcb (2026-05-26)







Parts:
C1, C4, C10, C28: 100n; C_0603_1608Metric; Voltage 100V; Part Number GRM188R72A104KA35D
C2, C3, C5, C6, C7, C26, C27, C29, C30, C31: 1uF; C_0603_1608Metric; Part Number CL10B105KP8NNNC
C8, C9, C32, C33: 100p; C_0603_1608Metric; Part Number GRM1885C1H101JA01D
D1, D2, D20, D21: 1N4148W; D_SOD-123; Part Number 1N4148W-7-F
D3, D22: MMSZ5268BT1G; D_SOD-123; Part Number MMSZ5268BT1G
D4, D23: LED; LED_0603_1608Metric_Pad1.05x0.95mm_HandSolder; Part Number VLMTG1400-GS08
F1, F18, F35, F37, F39, F41, F44, F46, F47, F49, F51, F55, F57, F59, F61, F63, F64, F66, F67: 50mA; Fuse_1206_3216Metric; Part Number 3413.0002.11
FB1, FB2: 33; R_0603_1608Metric; Part Number BLM18PG330SN1D
J1: PB MB 2; Molex_PicoBlade_53048-0210_1x02_P1.25mm_Horizontal; Part Number 53048-0210
J2: PA MA 2; Molex_PicoBlade_53048-0210_1x02_P1.25mm_Horizontal; Part Number 53048-0210
J3, J6: Sensors; Molex_PicoBlade_53048-1510_1x15_P1.25mm_Horizontal; Part Number 53048-1510
J4, J5: Conn_01x08; Molex_PicoBlade_53048-0810_1x08_P1.25mm_Horizontal; Part Number 53048-0810
J10: PB MB 1; Molex_PicoBlade_53048-0210_1x02_P1.25mm_Horizontal; Part Number 53048-0210
J11: PA MA 1; Molex_PicoBlade_53048-0210_1x02_P1.25mm_Horizontal; Part Number 53048-0210
Q1, Q17: DZTT5551; SOT-223; Part Number DZT5551-13
Q18, Q19, Q20, Q21, Q22, Q23, Q24, Q25, Q26, Q27, Q28, Q29, Q30, Q31, Q32: 2N7002; SOT-23; Part Number 2N7002
R1, R3, R8, R9, R74, R76, R81, R82, R84, R85, R86, R87, R88, R89, R90, R91, R92, R93, R94, R95, R96, R98, R99: 100; R_0805_2012Metric; Part Number CRCW0805100RFKEAHP
R2, R75: 806; R_0603_1608Metric; Part Number CRCW0603806RFKEA
R4, R77: 1M; R_0603_1608Metric; Part Number CRCW06031M00FKEA
R5, R10, R78, R83: 1.2k; R_0603_1608Metric; Part Number CRCW06031K20FKEA
R6, R7, R79, R80: 0; R_0603_1608Metric; Part Number CRCW06030000Z0EA
R11, R12, R16, R20, R24, R28, R32, R36, R40, R44, R48, R52, R56, R60, R64: 680; R_0603_1608Metric; Part Number RCS0603680RFKEA
R68, R72, R73, R97, R100, R101, R102, R103, R104, R105, R106, R107, R108, R109, R110: 3.3k; R_0508_1220Metric; Part Number WK73R2ATTD3301F
TR1, TR2: HM2102NL; Part Number HM2102NL
U1, U2: LTC6812-1; TQFP-64-1EP_10x10mm_P0.5mm_EP8x8mm; Part Number LTC6812-1

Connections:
/IMA_1: R9.1, TR1.12, U1.61 (CSB(IMA))
/IMA_2: R82.1, TR2.12, U2.61 (CSB(IMA))
/IMB_1: R8.1, TR1.9, U1.63 (IMB)
/IMB_2: R81.1, TR2.9, U2.63 (IMB)
/IPA_1: R9.2, TR1.10, U1.62 (SCK(IPA))
/IPA_2: R82.2, TR2.10, U2.62 (SCK(IPA))
/IPB_1: R8.2, TR1.7, U1.64 (IPB)
/IPB_2: R81.2, TR2.7, U2.64 (IPB)
/Vref1_1: C2.2, U1.51 (VREF1)
/Vref1_2: C26.2, U2.51 (VREF1)
/Vref2_1: C3.2, U1.50 (VREF2)
/Vref2_2: C27.2, U2.50 (VREF2)
/Vreg_1: C5.2, C6.2, C7.2, D4.2 (A), Q1.3 (E), R4.2, R6.1, U1.48 (VREG)
/Vreg_2: C29.2, C30.2, C31.2, D23.2 (A), Q17.3 (E), R77.2, R79.1, U2.48 (VREG)
/cell1/C: U1.36 (C1); also elsewhere on the board
/cell1/S: U1.37 (S1); also elsewhere on the board
/cell2/C: U1.34 (C2); also elsewhere on the board
/cell2/S: U1.35 (S2); also elsewhere on the board
/cell3/C: U1.32 (C3); also elsewhere on the board
/cell3/S: U1.33 (S3); also elsewhere on the board
/cell4/C: U1.30 (C4); also elsewhere on the board
/cell4/S: U1.31 (S4); also elsewhere on the board
/cell5/C: U1.28 (C5); also elsewhere on the board
/cell5/S: U1.29 (S5); also elsewhere on the board
/cell6/C: U1.24 (C6); also elsewhere on the board
/cell6/S: U1.25 (S6); also elsewhere on the board
/cell7/C: U1.22 (C7); also elsewhere on the board
/cell7/S: U1.23 (S7); also elsewhere on the board
/cell8/C: U1.20 (C8); also elsewhere on the board
/cell8/S: U1.21 (S8); also elsewhere on the board
/cell9/S: U1.19 (S9); also elsewhere on the board
/cell10/C: U1.16 (C10); also elsewhere on the board
/cell10/CM: U1.18 (C9); also elsewhere on the board
/cell10/S: U1.17 (S10); also elsewhere on the board
/cell11/C: U1.12 (C11); also elsewhere on the board
/cell11/S: U1.13 (S11); also elsewhere on the board
/cell12/C: U1.10 (C12); also elsewhere on the board
/cell12/S: U1.11 (S12); also elsewhere on the board
/cell13/C: U1.8 (C13); also elsewhere on the board
/cell13/S: U1.9 (S13); also elsewhere on the board
/cell14/C: U1.6 (C14); also elsewhere on the board
/cell14/S: U1.7 (S14); also elsewhere on the board
/cell15/C: U1.4 (C15); also elsewhere on the board
/cell15/S: U1.5 (S15); also elsewhere on the board
Cell_1+: J5.2, J6.3, Q18.3 (D); also elsewhere on the board
Cell_1-: C1.1, C2.1, C3.1, C4.1, C5.1, C6.1, C7.1, C8.1, C9.1, C10.1, C26.1, C27.1, C28.1, C29.1, C30.1, C31.1, C32.1, C33.1, D1.2 (A), D2.2 (A), D3.2 (A), D20.2 (A), D21.2 (A), D22.2 (A), J5.1, J6.1, R2.2, R7.1, R10.2, R75.2, R80.1, R83.2, U1.38 (C0), U1.59 (V-**), U1.60 (V-*), U1.65 (V-), U2.38 (C0), U2.59 (V-**), U2.60 (V-*), U2.65 (V-); also elsewhere on the board
Cell_2+: J5.3, J6.5, Q19.3 (D); also elsewhere on the board
Cell_3+: J5.4, J6.7, Q20.3 (D); also elsewhere on the board
Cell_4+: J5.5, J6.9, Q21.3 (D); also elsewhere on the board
Cell_5+: J5.6, J6.11, Q22.3 (D); also elsewhere on the board
Cell_6+: J5.7, J6.13, Q23.3 (D); also elsewhere on the board
Cell_7+: J5.8, J6.15, Q24.3 (D); also elsewhere on the board
Cell_8+: J3.14, J4.1, Q25.3 (D); also elsewhere on the board
Cell_9+: J3.12, J4.2, Q26.3 (D); also elsewhere on the board
Cell_10+: J3.10, J4.3, Q27.3 (D); also elsewhere on the board
Cell_11+: J3.8, J4.4, Q28.3 (D); also elsewhere on the board
Cell_12+: J3.6, J4.5, Q29.3 (D); also elsewhere on the board
Cell_13+: J3.4, J4.6, Q30.3 (D); also elsewhere on the board
Cell_14+: J3.2, J4.7, Q31.3 (D); also elsewhere on the board
Cell_15+: FB1.2, FB2.2, J4.8, Q32.3 (D); also elsewhere on the board
ISO_1A_N: J10.2, TR1.4
ISO_1A_P: J10.1, TR1.6
ISO_1B_N: J11.2, TR1.1
ISO_1B_P: J11.1, TR1.3
ISO_2A_N: J2.1, TR2.4
ISO_2A_P: J2.2, TR2.6
ISO_2B_N: J1.1, TR2.1
ISO_2B_P: J1.2, TR2.3
Meas1+: J6.2, R11.2, R98.1
Meas2+: J6.4, R12.2, R99.1
Meas3+: J6.6, R16.2, R96.2
Meas4+: J6.8, R20.2, R95.2
Meas5+: J6.10, R24.2, R94.2
Meas6+: J6.12, R28.2, R93.2
Meas7+: J6.14, R36.2, R92.2
Meas8+: J3.15, R40.2, R91.2
Meas9+: J3.13, R32.2, R90.2
Meas10+: J3.11, R52.2, R89.2
Meas11+: J3.9, R44.2, R88.2
Meas12+: J3.7, R48.2, R87.2
Meas13+: J3.5, R56.2, R86.2
Meas14+: J3.3, R60.2, R85.2
Meas15+: J3.1, R64.2, R84.2
unnamed: C4.2, F18.2, Q1.2 (C), Q1.4 (C)
unnamed: C8.2, TR1.8
unnamed: C9.2, TR1.11
unnamed: C28.2, F66.1, Q17.2 (C), Q17.4 (C)
unnamed: C32.2, TR2.8
unnamed: C33.2, TR2.11
unnamed: D1.1 (K), D2.1 (K), D3.1 (K), FB1.1, R1.2, R3.2
unnamed: D4.1 (K), R10.1
unnamed: D20.1 (K), D21.1 (K), D22.1 (K), FB2.1, R74.2, R76.2
unnamed: D23.1 (K), R83.1
unnamed: F1.1, R1.1
unnamed: F18.1, R3.1
unnamed: F35.2, R90.1
unnamed: F37.2, R91.1
unnamed: F39.2, R92.1
unnamed: F41.2, R93.1
unnamed: F44.2, R95.1
unnamed: F46.2, R96.1
unnamed: F47.2, R94.1
unnamed: F49.2, R99.2
unnamed: F51.2, R98.2
unnamed: F55.1, R88.1
unnamed: F57.1, R87.1
unnamed: F59.1, R86.1
unnamed: F61.1, R85.1
unnamed: F63.1, R84.1
unnamed: F64.1, R89.1
unnamed: F66.2, R76.1
unnamed: F67.1, R74.1
unnamed: Q1.1 (B), U1.49 (DRIVE)
unnamed: Q17.1 (B), U2.49 (DRIVE)
unnamed: Q18.1 (G), R68.2
unnamed: Q18.2 (S), R11.1
unnamed: Q19.1 (G), R72.2
unnamed: Q19.2 (S), R12.1
unnamed: Q20.1 (G), R73.2
unnamed: Q20.2 (S), R16.1
unnamed: Q21.1 (G), R97.2
unnamed: Q21.2 (S), R20.1
unnamed: Q22.1 (G), R100.2
unnamed: Q22.2 (S), R24.1
unnamed: Q23.1 (G), R101.2
unnamed: Q23.2 (S), R28.1
unnamed: Q24.1 (G), R102.2
unnamed: Q24.2 (S), R36.1
unnamed: Q25.1 (G), R103.2
unnamed: Q25.2 (S), R40.1
unnamed: Q26.1 (G), R104.2
unnamed: Q26.2 (S), R32.1
unnamed: Q27.1 (G), R105.2
unnamed: Q27.2 (S), R52.1
unnamed: Q28.1 (G), R106.2
unnamed: Q28.2 (S), R44.1
unnamed: Q29.1 (G), R107.2
unnamed: Q29.2 (S), R48.1
unnamed: Q30.1 (G), R108.2
unnamed: Q30.2 (S), R56.1
unnamed: Q31.1 (G), R109.2
unnamed: Q31.2 (S), R60.1
unnamed: Q32.1 (G), R110.2
unnamed: Q32.2 (S), R64.1
unnamed: R7.2, U1.52 (DTEN)
unnamed: R5.1, U1.57 (IBIAS)
unnamed: R2.1, R5.2, U1.58 (ICMP)
unnamed: R6.2, U1.55 (ISOMD)
unnamed: C1.2, F1.2, U1.1 (V+)
unnamed: R4.1, U1.56 (WDT)
unnamed: F51.1, U2.36 (C1)
unnamed: F49.1, U2.34 (C2)
unnamed: F46.1, U2.32 (C3)
unnamed: F44.1, U2.30 (C4)
unnamed: F47.1, U2.28 (C5)
unnamed: F41.1, U2.24 (C6)
unnamed: F39.1, U2.22 (C7)
unnamed: F37.1, U2.20 (C8)
unnamed: F35.1, U2.18 (C9)
unnamed: F64.2, U2.16 (C10)
unnamed: F55.2, U2.12 (C11)
unnamed: F57.2, U2.10 (C12)
unnamed: F59.2, U2.8 (C13)
unnamed: F61.2, U2.6 (C14)
unnamed: F63.2, U2.4 (C15)
unnamed: R80.2, U2.52 (DTEN)
unnamed: R78.1, U2.57 (IBIAS)
unnamed: R75.1, R78.2, U2.58 (ICMP)
unnamed: R79.2, U2.55 (ISOMD)
unnamed: C10.2, F67.2, U2.1 (V+)
unnamed: R77.1, U2.56 (WDT)
S1: R68.1, U2.37 (S1)
S2: R72.1, U2.35 (S2)
S3: R73.1, U2.33 (S3)
S4: R97.1, U2.31 (S4)
S5: R100.1, U2.29 (S5)
S6: R101.1, U2.25 (S6)
S7: R102.1, U2.23 (S7)
S8: R103.1, U2.21 (S8)
S9: R104.1, U2.19 (S9)
S10: R105.1, U2.17 (S10)
S11: R106.1, U2.13 (S11)
S12: R107.1, U2.11 (S12)
S13: R108.1, U2.9 (S13)
S14: R109.1, U2.7 (S14)
S15: R110.1, U2.5 (S15)

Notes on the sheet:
Differential pair
Per Cell stack configuration for Temperature measurement
Need pulldown
Cell Voltage and Balancing
Tie Meas- to Cell-
C0 does not require a 50mA fuse, since there are no other components to protect
Cell+ tap through bias resistor to Meas+ pin
Proposed Temperature Sensing circuit
IsoSPI transformer link

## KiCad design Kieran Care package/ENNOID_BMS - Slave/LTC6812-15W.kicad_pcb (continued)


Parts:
C25: 100n; C_0603_1608Metric; Voltage 100V; Part Number GRM188R72A104KA35D
D19: PDZ7.5B; D_SOD-323; Part Number PDZ7.5B
F3: 50mA; Fuse_1206_3216Metric; Part Number 3413.0002.11
Q16: TSM2323; SOT-23; Part Number TSM2323CX RFG
R69: 22; R_2512_6332Metric; Part Number AC2512JK-7W22RL
R70: 3.3k; R_0508_1220Metric; Part Number WK73R2ATTD3301F
R71: 100; R_0805_2012Metric; Part Number CRCW0805100RFKEAHP

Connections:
/cell14/C: D19.2 (A); also elsewhere on the board
/cell15/C: C25.2, D19.1 (K), F3.2; also elsewhere on the board
/cell15/S: R70.1; also elsewhere on the board
Cell_1-: C25.1; also elsewhere on the board
Cell_14+: R69.1; also elsewhere on the board
Cell_15+: Q16.2 (S), R71.2; also elsewhere on the board
unnamed: F3.1, R71.1
unnamed: Q16.3 (D), R69.2
unnamed: Q16.1 (G), R70.2

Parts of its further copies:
C11, C12, C13, C14, C15, C16, C17, C18, C19, C20, C21, C22, C23, C24: 100n; C_0603_1608Metric; Voltage 100V; Part Number GRM188R72A104KA35D
D5, D6, D7, D8, D9, D10, D11, D12, D13, D14, D15, D16, D17, D18: PDZ7.5B; D_SOD-323; Part Number PDZ7.5B
F5, F7, F9, F11, F13, F15, F20, F22, F24, F26, F28, F30, F32, F34: 50mA; Fuse_1206_3216Metric; Part Number 3413.0002.11
Q2, Q3, Q4, Q5, Q6, Q7, Q8, Q9, Q10, Q11, Q12, Q13, Q14, Q15: TSM2323; SOT-23; Part Number TSM2323CX RFG
R13, R17, R21, R25, R29, R33, R37, R41, R45, R49, R53, R57, R61, R65: 22; R_2512_6332Metric; Part Number AC2512JK-7W22RL
R14, R18, R22, R26, R30, R34, R38, R42, R46, R50, R54, R58, R62, R66: 3.3k; R_0508_1220Metric; Part Number WK73R2ATTD3301F
R15, R19, R23, R27, R31, R35, R39, R43, R47, R51, R55, R59, R63, R67: 100; R_0805_2012Metric; Part Number CRCW0805100RFKEAHP

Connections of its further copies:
/cell1/C: C11.2, D5.1 (K), D6.2 (A), F34.2; also elsewhere on the board
/cell1/S: R14.1; also elsewhere on the board
/cell2/C: C12.2, D6.1 (K), D7.2 (A), F32.2; also elsewhere on the board
/cell2/S: R18.1; also elsewhere on the board
/cell3/C: C13.2, D7.1 (K), D8.2 (A), F30.2; also elsewhere on the board
/cell3/S: R22.1; also elsewhere on the board
/cell4/C: C14.2, D8.1 (K), D9.2 (A), F28.2; also elsewhere on the board
/cell4/S: R26.1; also elsewhere on the board
/cell5/C: C15.2, D9.1 (K), D10.2 (A), F26.2; also elsewhere on the board
/cell5/S: R30.1; also elsewhere on the board
/cell6/C: C16.2, D10.1 (K), D11.2 (A), F24.2; also elsewhere on the board
/cell6/S: R34.1; also elsewhere on the board
/cell7/C: C17.2, D11.1 (K), D12.2 (A), F22.2; also elsewhere on the board
/cell7/S: R38.1; also elsewhere on the board
/cell8/C: C18.2, D12.1 (K), D13.2 (A), F20.2; also elsewhere on the board
/cell8/S: R42.1; also elsewhere on the board
/cell9/S: R46.1; also elsewhere on the board
/cell10/C: C20.2, D14.1 (K), D15.2 (A), F13.2; also elsewhere on the board
/cell10/CM: C19.2, D13.1 (K), D14.2 (A), F15.2; also elsewhere on the board
/cell10/S: R50.1; also elsewhere on the board
/cell11/C: C21.2, D15.1 (K), D16.2 (A), F11.2; also elsewhere on the board
/cell11/S: R54.1; also elsewhere on the board
/cell12/C: C22.2, D16.1 (K), D17.2 (A), F9.2; also elsewhere on the board
/cell12/S: R58.1; also elsewhere on the board
/cell13/C: C23.2, D17.1 (K), D18.2 (A), F7.2; also elsewhere on the board
/cell13/S: R62.1; also elsewhere on the board
/cell14/C: C24.2, D18.1 (K), F5.2; also elsewhere on the board
/cell14/S: R66.1; also elsewhere on the board
Cell_1+: Q2.2 (S), R15.2, R17.1; also elsewhere on the board
Cell_1-: C11.1, C12.1, C13.1, C14.1, C15.1, C16.1, C17.1, C18.1, C19.1, C20.1, C21.1, C22.1, C23.1, C24.1, D5.2 (A), R13.1; also elsewhere on the board
Cell_2+: Q3.2 (S), R19.2, R21.1; also elsewhere on the board
Cell_3+: Q4.2 (S), R23.2, R25.1; also elsewhere on the board
Cell_4+: Q5.2 (S), R27.2, R29.1; also elsewhere on the board
Cell_5+: Q6.2 (S), R31.2, R33.1; also elsewhere on the board
Cell_6+: Q7.2 (S), R35.2, R37.1; also elsewhere on the board
Cell_7+: Q8.2 (S), R39.2, R41.1; also elsewhere on the board
Cell_8+: Q9.2 (S), R43.2, R45.1; also elsewhere on the board
Cell_9+: Q10.2 (S), R47.2, R49.1; also elsewhere on the board
Cell_10+: Q11.2 (S), R51.2, R53.1; also elsewhere on the board
Cell_11+: Q12.2 (S), R55.2, R57.1; also elsewhere on the board
Cell_12+: Q13.2 (S), R59.2, R61.1; also elsewhere on the board
Cell_13+: Q14.2 (S), R63.2, R65.1; also elsewhere on the board
Cell_14+: Q15.2 (S), R67.2; also elsewhere on the board
unnamed: F5.1, R67.1
unnamed: F7.1, R63.1
unnamed: F9.1, R59.1
unnamed: F11.1, R55.1
unnamed: F13.1, R51.1
unnamed: F15.1, R47.1
unnamed: F20.1, R43.1
unnamed: F22.1, R39.1
unnamed: F24.1, R35.1
unnamed: F26.1, R31.1
unnamed: F28.1, R27.1
unnamed: F30.1, R23.1
unnamed: F32.1, R19.1
unnamed: F34.1, R15.1
unnamed: Q2.3 (D), R13.2
unnamed: Q2.1 (G), R14.2
unnamed: Q3.3 (D), R17.2
unnamed: Q3.1 (G), R18.2
unnamed: Q4.3 (D), R21.2
unnamed: Q4.1 (G), R22.2
unnamed: Q5.3 (D), R25.2
unnamed: Q5.1 (G), R26.2
unnamed: Q6.3 (D), R29.2
unnamed: Q6.1 (G), R30.2
unnamed: Q7.3 (D), R33.2
unnamed: Q7.1 (G), R34.2
unnamed: Q8.3 (D), R37.2
unnamed: Q8.1 (G), R38.2
unnamed: Q9.3 (D), R41.2
unnamed: Q9.1 (G), R42.2
unnamed: Q10.3 (D), R45.2
unnamed: Q10.1 (G), R46.2
unnamed: Q11.3 (D), R49.2
unnamed: Q11.1 (G), R50.2
unnamed: Q12.3 (D), R53.2
unnamed: Q12.1 (G), R54.2
unnamed: Q13.3 (D), R57.2
unnamed: Q13.1 (G), R58.2
unnamed: Q14.3 (D), R61.2
unnamed: Q14.1 (G), R62.2
unnamed: Q15.3 (D), R65.2
unnamed: Q15.1 (G), R66.2

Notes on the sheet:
Love to see Cathal's miracle fuses in action



Board: 2 copper layers, 73.4 x 117.4 mm, 246 parts (104 on the bottom side), 231 nets.

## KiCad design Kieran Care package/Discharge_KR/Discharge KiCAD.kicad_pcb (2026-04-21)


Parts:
C1, C4: 1uF; FA18X7R1H104KNU00; Part Number FA18X7R1E105KRU00
D1: 1N4001; D_DO-41_SOD81_P10.16mm_Horizontal; Part Number 1N4001
D3: 1N4148; D_DO-35_SOD27_P7.62mm_Horizontal; Part Number 1N4148
J1, J2: Conn_01x02; Phoenix_1x2_1729128; Part Number 1729128
J3: Conn_01x02; JST_XH_B2B-XH-A_1x02_P2.50mm_Vertical; Part Number B2B-XH-A
J4: Conn_01x03; JST_XH_B3B-XH-A_1x03_P2.50mm_Vertical; Part Number B3B-XH-A
K1: DBR71210; Part Number DBR71210
R3: 10k; R_Axial_DIN0207_L6.3mm_D2.5mm_P10.16mm_Horizontal; Part Number MCF 0.25W 10K
R8, R9, R10, R11: 56k; R_Axial_DIN0207_L6.3mm_D2.5mm_P10.16mm_Horizontal; Part Number MCF 0.25W 56K
U1: MCP1703AT-3302E/MBVAO; SOT-89-3; Part Number MCP1703AT-3302E/MBVAO
U2: HCPL-817-000E; DIP-4_W7.62mm; Part Number HCPL-817-000E

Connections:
3.3V: C1.1, R3.2, U1.3 (VO)
Discharing_N: J4.1, R3.1, U2.4
GLV+: C4.1, J3.2, U1.2 (VI)
GLV-: C1.2, C4.2, D1.2 (A), J3.1, J4.2, K1.3, U1.1 (GND), U2.3
Load+: J2.2, K1.1
Load-: D3.2 (A), J1.2, J2.1, U2.2
unnamed: D3.1 (K), R11.2, U2.1
unnamed: J1.1, K1.2, R8.1
unnamed: R8.2, R9.1
unnamed: R9.2, R10.1
unnamed: R10.2, R11.1
SDWN_DC+: D1.1 (K), J4.3, K1.4

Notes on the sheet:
normally closed
TE HSC1002K7J 2.7 kOhm 100W Chassis Mount Resistor
Connects on Inverter side. Can use the BMS Master Load+ connector
HV LV


Board: 2 copper layers, 64.3 x 47.9 mm, 16 parts (0 on the bottom side), 12 nets.

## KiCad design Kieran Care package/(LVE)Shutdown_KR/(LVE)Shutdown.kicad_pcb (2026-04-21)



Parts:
C1: 0.22uF; FA14X7R1H224KNU00; Part Number FA14X7R1H224KNU00
C2, C6, C7: 0.1uF; FA18X7R1H104KNU00; Part Number FA18X7R1H104KNU00
D20, D21: 1N4001; D_DO-41_SOD81_P10.16mm_Horizontal; Part Number 1n4001
J1: Conn_01x03_Pin; JST_XH_B3B-XH-A_1x03_P2.50mm_Vertical; Part Number B3B-XH-A
J2, J3: Conn_01x06; JST_XH_B6B-XH-A_1x06_P2.50mm_Vertical; Part Number B6B-XH-A
J4: Conn_01x03; JST_XH_B3B-XH-A_1x03_P2.50mm_Vertical; Part Number B3B-XH-A
J5: IMD_RST; JST_XH_B2B-XH-A_1x02_P2.50mm_Vertical; Part Number B2B-XH-A
J6: AMS_RST; JST_XH_B2B-XH-A_1x02_P2.50mm_Vertical; Part Number B2B-XH-A
J7: HV_SENSE_INTL; JST_XH_B2B-XH-A_1x02_P2.50mm_Vertical; Part Number B2B-XH-A
J8: Conn_BSPD; JST_XH_B2B-XH-A_1x02_P2.50mm_Vertical; Part Number B2B-XH-A
J9: Conn_BTN_Cockpit; JST_XH_B2B-XH-A_1x02_P2.50mm_Vertical; Part Number B2B-XH-A
J10: Conn_BTN_Left; JST_XH_B2B-XH-A_1x02_P2.50mm_Vertical; Part Number B2B-XH-A
J11: Conn_BTN_Right; JST_XH_B2B-XH-A_1x02_P2.50mm_Vertical; Part Number B2B-XH-A
J12: Conn_BOTS_1; JST_XH_B2B-XH-A_1x02_P2.50mm_Vertical; Part Number B2B-XH-A
J13: Conn_BOTS_2; JST_XH_B2B-XH-A_1x02_P2.50mm_Vertical; Part Number B2B-XH-A
J14: Conn_Inertia; JST_XH_B2B-XH-A_1x02_P2.50mm_Vertical; Part Number B2B-XH-A
J15: Conn_HVD_INTL; JST_XH_B2B-XH-A_1x02_P2.50mm_Vertical; Part Number B2B-XH-A
J16: Conn_ACC_INTL; JST_XH_B2B-XH-A_1x02_P2.50mm_Vertical; Part Number B2B-XH-A
J17: Conn_TSMS; JST_XH_B2B-XH-A_1x02_P2.50mm_Vertical; Part Number B2B-XH-A
J18: Conn_discharge; JST_XH_B2B-XH-A_1x02_P2.50mm_Vertical; Part Number B2B-XH-A
J19: Conn_precharge; JST_XH_B2B-XH-A_1x02_P2.50mm_Vertical; Part Number B2B-XH-A
J20: Conn_Power; JST_XH_B2B-XH-A_1x02_P2.50mm_Vertical; Part Number B2B-XH-A
J21: Conn_AIR 1; JST_XH_B2B-XH-A_1x02_P2.50mm_Vertical; Part Number B2B-XH-A
J22: Conn_AIR 2; JST_XH_B2B-XH-A_1x02_P2.50mm_Vertical; Part Number B2B-XH-A
J23: Conn_TSAL_OK; JST_XH_B2B-XH-A_1x02_P2.50mm_Vertical; Part Number B2B-XH-A
J24: IMD_LED; JST_XH_B2B-XH-A_1x02_P2.50mm_Vertical; Part Number B2B-XH-A
J27: AMS_LED; JST_XH_B2B-XH-A_1x02_P2.50mm_Vertical; Part Number B2B-XH-A
K6, K7: G5Q1A4DC12; Relay_SPST_Omron-G5Q-1A; Part Number G5Q1A4DC12
LED1, LED2, LED3, LED4, LED5, LED6, LED7, LED8, LED9, LED10, LED11, LED12, LED13, LED14, LED15: LTL-1CHG; LTL1CHG; Mouser Part Number 859-LTL-1CHG
Q1, Q2, Q3, Q5: 2N7002; SOT-23; Part Number 2N7002
R1, R2, R3, R16, R17, R18, R19, R20, R21, R22, R23, R24, R25, R29, R53: 27k; R_Axial_DIN0207_L6.3mm_D2.5mm_P10.16mm_Horizontal; Part Number MCF 0.25W 27K
R4, R5, R6, R7, R8, R9, R10, R11, R13, R15, R28, R30, R31, R32, R33, R34, R35, R36, R37, R38, R39, R40, R41, R42, R43, R44, R45, R46, R47, R48, R49, R50, R52, R54, R55, R57, R59, R60: 10k; R_Axial_DIN0207_L6.3mm_D2.5mm_P10.16mm_Horizontal; Part Number MCF 0.25W 10K
R12, R14, R26, R27, R56, R58: 100; R_Axial_DIN0207_L6.3mm_D2.5mm_P10.16mm_Horizontal; Part Number MCF 0.25W 100
U1: LM7805MPX/NOPB; SOT-223-3_TabPin2; Part Number LM7805MPX/NOPB
U2: SN74AHC1G02DBVR; SOT-23-5; Part Number SN74AHC1G02DBVR
U6: MC74HC74ADG; SOIC-14_3.9x8.7mm_P1.27mm; Part Number MC74HC74ADG

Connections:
+5V: C2.1, C6.1, C7.2, J5.1, J6.2, R10.2, R11.2, R12.1, R27.1, U1.1 (VO), U2.5 (VCC), U6.2 (D), U6.12 (D), U6.14 (VCC)
A: K6.2, K7.3, R3.2, R60.2
AMS_LED+: J27.2, R27.2
AMS_LED-: J27.1, Q3.3 (D)
AMS_OK: U2.4, U6.13 (~R)
AMS_relay: R57.2, R58.2, U6.9 (Q)
AMS_reset: J6.1, U6.10 (~S)
B: J9.2, K7.2, R9.2, R16.2
Discharge enable: J1.1, R10.1, U2.2
GLVS+: C1.1, D20.1 (K), D21.1 (K), J8.1, J20.2, K6.1, K7.1, R1.2, R40.2, U1.3 (VI)
GLVS-: C1.2, C2.2, C6.2, C7.1, J18.1, J20.1, J21.1, J22.1, LED1.2 (K), LED2.2 (K), LED3.2 (K), LED4.2 (K), LED5.2 (K), LED6.2 (K), LED7.2 (K), LED8.2 (K), LED9.2 (K), LED10.2 (K), LED11.2 (K), LED12.2 (K), LED13.2 (K), LED14.2 (K), LED15.2 (K), Q1.2 (S), Q2.2 (S), Q3.2 (S), Q5.2 (S), R4.2, R5.2, R6.2, R8.2, R13.1, R15.1, R30.2, R31.2, R32.2, R33.2, R34.2, R35.2, R36.2, R37.2, R38.2, R39.2, R41.2, R54.2, R55.1, R57.1, U1.2 (GND), U2.3 (GND), U6.7 (GND)
IMD_IN: J8.2, K6.3, R2.2, R59.2
IMD_LED+: J24.2, R12.2
IMD_LED-: J24.1, Q2.3 (D)
IMD_OK: R7.2, R8.1, U6.1 (~R)
IMD_relay: R55.2, R56.2, U6.5 (Q)
IMD_reset: J5.2, U6.4 (~S)
Multi purpose enable: J1.2, R11.1, U2.1
unnamed: D20.2 (A), K6.5, Q5.3 (D)
unnamed: D21.2 (A), K7.5, Q1.3 (D)
unnamed: J2.1, R16.1, R30.1
unnamed: J2.2, R17.1, R31.1
unnamed: J2.3, R18.1, R32.1
unnamed: J2.4, R19.1, R33.1
unnamed: J2.5, R20.1, R34.1
unnamed: J2.6, R21.1, R35.1
unnamed: J3.1, R22.1, R36.1
unnamed: J3.2, R23.1, R37.1
unnamed: J3.3, R24.1, R38.1
unnamed: J3.4, R25.1, R39.1
unnamed: J3.5, R53.1, R54.1
unnamed: J3.6, R29.1, R41.1
unnamed: J4.1, R1.1, R4.1
unnamed: J4.2, R2.1, R5.1
unnamed: J4.3, R3.1, R6.1
unnamed: J10.1, J11.2, R18.2, R43.2
unnamed: J9.1, J10.2, R17.2, R42.2
unnamed: J11.1, J12.2, R19.2, R44.2
unnamed: J12.1, J13.2, R20.2, R45.2
unnamed: J13.1, J14.2, R21.2, R46.2
unnamed: J14.1, J15.2, R22.2, R47.2
unnamed: J15.1, J16.2, R23.2, R48.2
unnamed: J7.2, J16.1, R24.2, R49.2
unnamed: J17.1, J18.2, J19.2, J22.2, R29.2, R52.2
unnamed: J17.2, J23.1, R50.2, R53.2
unnamed: J19.1, J21.2
unnamed: J7.1, J23.2, R25.2, R28.2
unnamed: LED1.1 (A), R59.1
unnamed: LED2.1 (A), R60.1
unnamed: LED3.1 (A), R9.1
unnamed: LED4.1 (A), R42.1
unnamed: LED5.1 (A), R43.1
unnamed: LED6.1 (A), R44.1
unnamed: LED7.1 (A), R45.1
unnamed: LED8.1 (A), R46.1
unnamed: LED9.1 (A), R47.1
unnamed: LED10.1 (A), R48.1
unnamed: LED11.1 (A), R52.1
unnamed: LED12.1 (A), R50.1
unnamed: LED13.1 (A), R49.1
unnamed: LED14.1 (A), R40.1
unnamed: LED15.1 (A), R28.1
unnamed: Q1.1 (G), R58.1
unnamed: Q2.1 (G), R14.1
unnamed: Q3.1 (G), R26.1
unnamed: Q5.1 (G), R56.1
unnamed: R13.2, R14.2, U6.6 (~Q)
unnamed: R15.2, R26.2, U6.8 (~Q)
OK_HS: J1.3, R7.1

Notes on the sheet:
HV Sense Interlock
Discharge and multipurpose enable come from BMS master OK_HS comes from IMD
Pink is the main Shutdown Daisy Chain
Accumulator Connector Interlock
Right Side Shutdown Button
Brake System Plausibility Device
Left Side Shutdown Button
Brake Over-Travel Switch 1
Precharge to AIR1
Discharge Relay
Cockpit Shutdown Button
Inertia Switch
IMD LED
Brake Over-Travel Switch 2
Tractive System Master Switch
1 Shutdown powered 2 BSPD closed 3 IMD closed 4 AMS closed 5 Cockpit closed 6 Left side closed 7 Right Side Closed 8 Brake Over-Travel Switch 1 9 Brake Over-Travel Switch 2 10 Inertia Switch 11 High Voltage Disconnect Interlock 12 Accumulator Connector Interlock 13 HV Sense Interlock 14 TSAL OK 15 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
AMS LED
High Voltage Disconnect Interlock
AIR 2
TSAL OK Relay
5V LDO Regulator


Board: 2 copper layers, 83.7 x 92.2 mm, 114 parts (0 on the bottom side), 69 nets.

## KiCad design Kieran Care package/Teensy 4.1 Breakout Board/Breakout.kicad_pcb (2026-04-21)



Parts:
C1, C2, C3, C5, C6, C7, C8, C10: 0.1uF; FA18X7R1H104KNU00; Part Number FA18X7R1H104KNU00
C4, C9: 10uF; CP_Radial_D5.0mm_P2.50mm; Part Number ECE-A1EKA100I
C23: 22uF; RDEC71E226K3P1H03B; Part Number RDEC71E226K3P1H03B
D1: NUP3105LT3G; SOT-23; Part Number NUP3105LT3G
J1: CAN; JST_XH_B3B-XH-A_1x03_P2.50mm_Vertical; Part Number B3B-XH-A
J2: 12V Power; JST_XH_B2B-XH-A_1x02_P2.50mm_Vertical; Part Number B2B-XH-A
J3: APPS1; JST_XH_B3B-XH-A_1x03_P2.50mm_Vertical; Part Number B3B-XH-A
J4: APPS2; JST_XH_B3B-XH-A_1x03_P2.50mm_Vertical; Part Number B3B-XH-A
J5: Brake_Pressure_Front; JST_XH_B3B-XH-A_1x03_P2.50mm_Vertical; Part Number B3B-XH-A
J6: Brake_Pressure_Rear; JST_XH_B3B-XH-A_1x03_P2.50mm_Vertical; Part Number B3B-XH-A
J7: Nextion; JST_XH_B4B-XH-A_1x04_P2.50mm_Vertical; Part Number B4B-XH-A
J8: ESP32; JST_XH_B4B-XH-A_1x04_P2.50mm_Vertical; Part Number B4B-XH-A
J9: Brake_Light; JST_XH_B2B-XH-A_1x02_P2.50mm_Vertical; Part Number B2B-XH-A
J10: RTD_Speaker; JST_XH_B2B-XH-A_1x02_P2.50mm_Vertical; Part Number B2B-XH-A
J11: Current Sensor Power source; JST_XH_B2B-XH-A_1x02_P2.50mm_Vertical; Part Number B2B-XH-A
J12: RTD_button; JST_XH_B3B-XH-A_1x03_P2.50mm_Vertical; Part Number B3B-XH-A
JP1: SolderJumper_2_Open; SolderJumper-2_P1.3mm_Open_Pad1.0x1.5mm
L1: VLS3015CX-2R2M-1; VLS3015; Mouser Part Number 810-VLS3015CX-2R2M-1
Q1, Q3: 2N7002; SOT-23; Part Number 2N7002
R1, R3, R9, R11: 10k; R_Axial_DIN0207_L6.3mm_D2.5mm_P10.16mm_Horizontal; Part Number MCF 0.25W 10K
R2, R4, R10, R12: 20k; R_Axial_DIN0207_L6.3mm_D2.5mm_P10.16mm_Horizontal; Part Number CFR25SJT-52A20K
R5, R7, R19: 100; R_Axial_DIN0207_L6.3mm_D2.5mm_P10.16mm_Horizontal; Part Number MCF 0.25W 100
R6, R8, R17, R20: 100k; R_Axial_DIN0207_L6.3mm_D2.5mm_P10.16mm_Horizontal; Part Number MCF 0.25W 100K
R13, R14, R15, R16: 1k; R_Axial_DIN0207_L6.3mm_D2.5mm_P10.16mm_Horizontal; Part Number MCF 0.25W 1K
R18: 220; R_Axial_DIN0207_L6.3mm_D2.5mm_P10.16mm_Horizontal; Part Number MCF 0.25W 220
R_CAN_TERM1: 120; R_Axial_DIN0207_L6.3mm_D2.5mm_P10.16mm_Horizontal; Part Number MCF 0.25W 120; not fitted
U1: SN65HVD230; SOIC-8_3.9x4.9mm_P1.27mm; Part Number SN65HVD230
U3: Teensy4.1; Teensy41; Part Number Teensy4.1
U4: TPS62163DSG; WSON-8-1EP_2x2mm_P0.5mm_EP0.9x1.6mm_ThermalVias; Part Number TPS62163DSG
U5: MPU6050; Part Number MPU6050

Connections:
3.3V: C1.2, C2.2, U1.3 (VCC), U3.46 (3V3), U5.1 (VCC)
5V: C3.2, C9.1, C23.2, J3.1, J4.1, J5.1, J6.1, J7.1, J8.1, J11.1, L1.2, R17.1, U3.48 (VIN), U4.6 (VOS)
12V: C4.1, J2.1, J9.2, J10.1, U4.2 (VIN), U4.3 (EN)
APPS1: J3.2, R1.1
APPS1_3.3V: C5.1, R13.1, U3.36 (14_A0_TX3_SPDIF_OUT)
APPS2: J4.2, R3.1
APPS2_3.3V: C6.1, R14.1, U3.37 (15_A1_RX3_SPDIF_IN)
Brake_Front: J5.2, R9.1
Brake_Front_3.3V: C7.1, R15.1, U3.38 (16_A2_RX4_SCL1)
Brake_Light_EN: R5.1, U3.8 (6_OUT1D)
Brake_Rear: J6.2, R11.1
Brake_Rear_3.3V: C8.1, R16.1, U3.39 (17_A3_TX4_SDA1)
CAN1_RX: U1.4 (R), U3.45 (23_A9_CRX1_MCLK1)
CAN1_TX: U1.1 (D), U3.44 (22_A8_CTX1)
CANH: D1.1 (K), J1.2, R_CAN_TERM1.1, U1.7 (CANH)
CANL: D1.2 (K), J1.3, JP1.1 (A), U1.6 (CANL)
CAN_GND: C1.1, C2.1, C3.1, C4.2, C5.2, C6.2, C7.2, C8.2, C9.2, C10.2, C23.1, D1.3 (A), J1.1, J2.2, J3.3, J4.3, J5.3, J6.3, J7.4, J8.4, J11.2, J12.2, Q1.2 (S), Q3.2 (S), R2.2, R4.2, R6.1, R8.1, R10.2, R12.2, R20.1, U1.2 (GND), U1.8 (Rs), U3.47 (GND), U4.1 (PGND), U4.4 (AGND), U4.5 (FB), U4.9 (PAD), U5.3 (GND)
ESP32_RX: J8.3, U3.10 (8_TX2_IN1)
ESP32_TX: J8.2, U3.9 (7_RX2_OUT1A)
MPU_SCL: U3.41 (19_A5_SCL), U5.4 (SCL)
MPU_SDA: U3.40 (18_A4_SDA), U5.5 (SDA)
unnamed: J9.1, Q3.3 (D)
unnamed: J10.2, Q1.3 (D)
unnamed: C10.1, J12.1, R18.2
unnamed: J12.3, R19.2, R20.2
unnamed: JP1.2 (B), R_CAN_TERM1.2
unnamed: Q1.1 (G), R7.2, R8.2
unnamed: Q3.1 (G), R5.2, R6.2
unnamed: R1.2, R2.1, R13.2
unnamed: R9.2, R10.1, R15.2
unnamed: R11.2, R12.1, R16.2
unnamed: R3.2, R4.1, R14.2
unnamed: R17.2, U4.8 (PG)
unnamed: L1.1, U4.7 (SW)
Nextion_RX: J7.3, U3.3 (1_TX1_CTX2_MISO1)
Nextion_TX: J7.2, U3.2 (0_RX1_CRX2_CS1)
Precharge_EN: R19.1, U3.5 (3_LRCLK2)
RTD_Speaker_EN: R7.1, U3.11 (9_OUT1C)
RTD_button: R18.1, U3.4 (2_OUT2)

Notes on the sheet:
2.2uH
brake and RTD button pressed together
Nextion TX to Teensy RX Teensy TX to Nextion RX
LP Filter should be physically close to Teensy
RS to GND for High Speed mode
120 Ω CAN termination Populate only if this PCB is end-of-bus
check current
Brake Light, Speaker, and RTD button
UART Interface
Analogue Sensors
Serial 1
Button contacts
MPU Sensor
VIN and VUSB link on Teensy 4.1 should be cut to avoid back-feeding
Serial 2
no pull up resistors necessary for adafruit mpu6050
22uF cap in TSAL BOM
CAN TVS Protection Diode
Will be mounted on socket 2x24 and some others
Assuming M7100, and scaling down to 3.3V
Pin 1: Red wire Pin 2: Black Wire
CAN Transceiver
ESP32 TX to Teensy RX Teensy TX to ESP32 RX
Teensy 4.1 Microcontroller
Buck Converter
all ADC signals need a return ground to prevent ground offset and jitter. Ground locally at chassis is not a good idea


Board: 2 copper layers, 81.4 x 64.3 mm, 53 parts (0 on the bottom side), 39 nets.

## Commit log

2025-09-11 Add Teensy Breakout Board
2025-09-11 Add work in progress breakout board for new Teensy microcontroller
2025-09-11 Add Teensy 4.1 Breakout Board KiCad project
    Added new KiCad schematic, PCB, and project files for the Teensy 4.1 Breakout Board. Removed old submodules for the previous Teensy Breakout Board design.
    [Breakout.kicad_pcb, Breakout.kicad_sch]
2025-09-11 Add comprehensive README for UCDFS KiCad circuits repository (#1)
    * Initial plan
    * Add comprehensive README.md for UCFS KiCad circuits repository
    * Update organization name from UCFS to UCDFS throughout README
    ---------
2025-09-11 Keelan Test
    [Breakout.kicad_sch]
2025-09-13 added existing circuits
    [(LVE)Shutdown BOM.csv, (LVE)Shutdown BOM_smd.xlsx, (LVE)Shutdown.kicad_pcb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]
2026-01-22 breakout board v1 sizing
    [Breakout.kicad_pcb, Breakout.kicad_sch, MPL3115A2.f3d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]
2026-01-22 breakout complete
    [Breakout.kicad_pcb, Breakout.kicad_sch]
2026-01-30 breakout updated and ENNOID BMS added
    [BMS-Master.kicad_sch, Breakout.kicad_pcb, Breakout.kicad_sch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]
2026-02-02 precharge complete
    [Breakout.kicad_pcb, Pre-charge KiCAD.kicad_pcb, Pre-charge KiCAD.kicad_sch]
2026-02-04 precharge and discharge fixed
    [Discharge KiCAD.kicad_pcb, Discharge KiCAD.kicad_sch, LTC6812-15W.kicad_sch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]
2026-02-06 Voltage measurement completed
    [BMS-Master.kicad_pcb, Battery Temperature Sensor BOM.csv, Battery Temperature Sensor.kicad_pcb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]
2026-02-06 added HVLV labels
    [Discharge KiCAD.kicad_pcb, Voltage_Measurement_KR.kicad_pcb]
2026-02-09 updated breakout
    [1051330001.stp, 70543-0001.stp, 705430004.stp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]
2026-02-12 ENNOID BMS PCBs completed
    [BMS-Master.kicad_pcb, BMS-Master.kicad_sch, CAN.kicad_sch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]
2026-02-15 slave pcb complete
    [LTC6812-15W.kicad_pcb, LTC6812-15W.kicad_sch]
2026-03-06 slave with new fuses added
    [BMS-Master.kicad_pcb, BSPD KiCAD.kicad_pcb, Breakout.csv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]
2026-03-07 bms architecture notes made re charging and discharging
    [BMS-Master.kicad_sch, LTC6812-15W.kicad_pcb, MCU.kicad_sch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]
2026-04-21 Slave with SMD and no other fuses
    [(LVE)Shutdown BOM.csv, (LVE)Shutdown BOM_smd.csv, (LVE)Shutdown BOM_smd.xlsx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]
2026-04-23 fused slave variant v1
    [LTC6812-15W.kicad_pcb, LTC6812-15W.kicad_sch, cell.kicad_sch]
2026-05-12 fuse boards
    [BMS-Master-B_Cu.gbr, BMS-Master-B_Mask.gbr, BMS-Master-B_Paste.gbr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]
2026-05-21 master and slave updated
    [BMS-Master.csv, BMS-Master.kicad_pcb, BMS-Master.kicad_sch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]
2026-05-24 new cells and updated slave
    [BMS-Master.kicad_pcb, BMS-Master.kicad_sch, BMS-Master.step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]
2026-05-24 added author
    [(LVE)Shutdown.kicad_sch, BMS-Master.kicad_sch, Breakout.kicad_sch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]
2026-05-26 ordered boards
    [LTC6812-15W.kicad_pcb]
2026-07-09 updated comments
    [(LVE)Shutdown.kicad_pcb, (LVE)Shutdown.kicad_sch, APPS final.kicad_pcb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]
2026-07-09 bspd comments
    [BSPD KiCAD.kicad_sch]
2026-10-12 Create Eurocircuits_STANDARD_pool_AIMADE_NOTCHECKED
    Parameters put together by Claude opus 5.5 max thinking model for Eurocircuits PCBs, they have yet to be checked by anyone.

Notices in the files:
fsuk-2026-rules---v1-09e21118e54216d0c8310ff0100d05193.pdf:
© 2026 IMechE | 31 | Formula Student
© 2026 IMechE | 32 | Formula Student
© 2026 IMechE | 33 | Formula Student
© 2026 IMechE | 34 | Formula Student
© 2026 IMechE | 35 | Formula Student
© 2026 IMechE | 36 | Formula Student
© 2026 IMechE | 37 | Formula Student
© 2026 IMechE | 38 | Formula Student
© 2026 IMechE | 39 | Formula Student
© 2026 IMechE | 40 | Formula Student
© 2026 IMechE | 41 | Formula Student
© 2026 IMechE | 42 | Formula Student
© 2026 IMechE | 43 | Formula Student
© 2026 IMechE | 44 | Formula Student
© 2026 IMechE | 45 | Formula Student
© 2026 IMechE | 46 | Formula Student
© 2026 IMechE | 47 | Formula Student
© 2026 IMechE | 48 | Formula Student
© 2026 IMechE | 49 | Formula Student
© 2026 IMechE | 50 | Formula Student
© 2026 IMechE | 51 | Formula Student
